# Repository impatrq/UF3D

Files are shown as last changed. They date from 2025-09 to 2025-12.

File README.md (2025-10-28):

# Bienvenido a UpFeet

<p align="center">
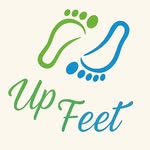
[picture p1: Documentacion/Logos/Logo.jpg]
UpFeet Logo
  
</p>

<div align="center">

🔗 Visitanos en  
👉 <a href="vzaccari33.wixsite.com/upfeet" target="_blank" rel="noopener noreferrer"><strong>nuestra pagina web</strong></a>

<br><br>

<a href="https://www.instagram.com/upfeet.3d/" target="_blank" rel="noopener noreferrer">
  Instagram
  @upfeet
</a>

</div>

---

## Nuestra Propuesta

**UpFeet3D** es un proyecto que desarrolla un escáner de pies basado en tecnología LiDAR y un sistema de ejes motorizados que permiten generar un modelo 3D preciso de la anatomía del pie. A partir de este escaneo, se diseña de manera automática una plantilla ortopédica personalizada que luego es fabricada mediante impresión 3D, ofreciendo una solución innovadora, accesible y adaptada a cada usuario.

---

## Cómo surgió el proyecto

El proyecto surgió a partir de la necesidad de brindar una solución a los pilotos y tripulaciones aéreas, quienes pasan largas horas sentados en condiciones que, sumadas a una mala pisada, pueden afectar la postura, generar dolores en la columna y aumentar la fatiga. Para atender esta problemática se diseñó un escáner portátil, que permite a una aerolínea contar con una sola máquina capaz de realizar plantillas personalizadas a todos sus empleados, reduciendo costos y facilitando la implementación. Con el tiempo, el desarrollo se proyectó también para otros usos, ofreciendo beneficios a cualquier persona que requiera una corrección postural o mayor confort en su andar.

---

## Características Principales

- Impresión 3D  
- Configuración por pantalla táctil  
- Escaneo 3D LiDAR  
- Sistema de ejes  
- Portátil  
- Económico  
- Rápido  

---

## Integrantes

- Melina Alfonso  
- Agustín Azorín  
- Eugenio Herrera  
- Tiago López  
- Victoria Viva  
- Valentín Zaccari  

---

## Información de Contacto

🌐 Sitio web oficial: [UpFeet Web](vzaccari33.wixsite.com/upfeet)  
📸 Instagram: [@UpFeet](https://www.instagram.com/upfeet.3d/) 📱🙌🎉  
📧 Correo: **upfeet3d@gmail.com**

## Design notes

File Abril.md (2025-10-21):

## Mes de Abril

**Objetivos del mes:**  
-  Crear todas los medios para publicar nuestos avances
-  Conseguir sponsors
-  Establecer los principios teoricos del proyecto

**Actividades realizadas:**  
-  Se creo la pagina web del proyecto
-  Se vrearon las redes sociales del proyecto
-  Se terminaron los objetivos de logro
-  Se termino el anteproyecto
-  Se subio infomacion del proyecto a las redes sociales
-  Se contacto via mail a diferentes empresas par buscar patrocinio
-  Se comenzo a investigar elementos necsarios para el proyecto
-  Se diseo como va a ser la estrucutra de la impresora

**Resultados obtenidos:**  
-  Se logro profundizar la interaccion con organismos como ortopedia IOA, ortopedia Pelaez, MicroElectronica, TP3D, ProyectoColor, Electrocomponentes S.A, etc.
-  Se consiguio materiales como los filamentos 3D, de parte de proyecto color, para el proyecto
-  Se consiguio algo de apoyo por parte de las reds sociales
-  El anteproyecto fue aprobado
-  Se decidio usar una Kinect ONE para la camara dl escaner
-  Se decidio usar FSR para los sensores de presion
-  Se decidio que materiales habria que usar para la construccion de la impresora

**Dificultades encontradas:**  
-  No se pudo lograr cubrir todo el proyecto a base de patrocinios

---

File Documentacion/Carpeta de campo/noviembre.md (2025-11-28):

## Mes de Noviembre

### Semana 1: Migración a Pi Pico y Fabricación de Nueva Placa de Control

**Objetivo de la semana:**
* Resolver la inestabilidad recurrente de la Raspberry Pi 4 (Pi 4) y migrar a un microcontrolador más fiable para la etapa de control.
* Diseñar y fabricar la nueva placa de control.

**Actividades realizadas:**
* Se realizaron pruebas para estabilizar la Pi 4 intentando el arranque a través de la salida **Micro HDMI** a monitores, pero la inestabilidad regresó después de poco tiempo.
* Se tomó la decisión de cambiar de microcontrolador, optando por la **Raspberry Pi Pico** debido a que se percibía como más simple y confiable para las tareas de control de motores.
* Se diseñó y se fabricó una **nueva placa de cobre** adaptada a la **Pi Pico**.
* En el nuevo diseño se tomaron medidas para mejorar la fiabilidad: se **agrandaron las pistas** y se hicieron las conexiones más cómodas.

**Resultados obtenidos:**
* Se decidió la **migración completa** del control de motores a la Pi Pico.
* Se completó el diseño y la fabricación de la **placa de control adaptada** al nuevo microcontrolador.

**Dificultades encontradas:**
* La persistente inestabilidad del *boot* y las conexiones de pines de la Raspberry Pi 4.

**Próximos pasos:**
* Probar la funcionalidad de los drivers y motores con la nueva placa.

***

### Semana 2: Control Estable de Motores, Integración LiDAR y Primeras Impresiones

**Objetivo de la semana:**
* Lograr el control total y estable de motores y sensor en la Pi Pico.
* Iniciar el testeo y la calibración de la impresora 3D.

**Actividades realizadas:**
* **Control de Motores:** Una vez fabricada la placa, se probaron los drivers y funcionaron perfectamente, **moviendo hasta dos motores paso a paso a la vez**. Se identificó que faltaba un driver operativo, se compró un reemplazo y, una vez instalado, **los tres motores funcionaron sin problemas**.
* **Integración LiDAR:** Se intentó testear el sensor LiDAR en la Pi Pico y **no funcionaba** (a pesar de funcionar en la Pi 4), un problema que resultó ser inusual. Tras diversas pruebas con códigos e invirtiendo el cableado, se descubrió que la única manera de que funcionara era **puentear el TX y RX del mismo LiDAR**. Esta corrección permitió seguir avanzando con el testeo del sensor.
* **Impresora 3D:** Se realizaron las primeras pruebas de impresión y **calibración** para el filamento **PETG**. Posteriormente, se realizó el **cambio de filamento a PLA**, con la calibración específica requerida para este material.

**Resultados obtenidos:**
* **Control de tres motores estable** y funcionando correctamente con la Pi Pico.
* Se implementó una **solución de *hardware*** (puenteo TX/RX) para el sensor LiDAR.
* Se **calibró la impresora** para los filamentos PETG y PLA.

**Dificultades encontradas:**
* Problema de comunicación inexplicable del LiDAR con la Pi Pico.

**Próximos pasos:**
* Fabricar los componentes mecánicos de acople

***

### Semana 3: Solución Mecánica Ingeniosa y Montaje Final del Escáner

**Objetivo de la semana:**
* Resolver los problemas de acoplamiento mecánico y ensamblar el sistema de escaneo completo.

**Actividades realizadas:**
* **Diseño e Impresión 3D:** Se diseñaron **tres acoples en AutoCAD** para las varillas roscadas de los ejes X e Y, y se buscaron y modificaron **dos soportes** para las varillas del eje Y. Todas estas piezas fueron **impresas en 3D con filamento PLA**.
* **Problema Anti-Backlash:** La **tuerca *anti-backlash* comprada no encajaba** con las varillas roscadas.
* **Solución Ingeniosa:** Se compraron **arandelas con tuercas a rosca** que sí coincidían con la varilla. Se procedió a **soldar la tuerca a la arandela** con un soldador eléctrico.
* Esta solución casera funcionó perfectamente, permitiendo que la varilla realizara los **movimientos horizontales y verticales** para el sensor LiDAR sin juego.
* **Ensamblaje Final:** Finalmente, se procedió a **unir y montar todo el escáner**, integrando la Pi Pico, los motores, el LiDAR y la estructura de ejes en H.

**Resultados obtenidos:**
* Se creó una **solución mecánica funcional y económica** para el problema de la tuerca *anti-backlash*.
* El **escáner fue completamente ensamblado y montado** en su estructura final.

**Dificultades encontradas:**
* Incompatibilidad de la tuerca *anti-backlash* comprada.

**Próximos pasos:**
* Pruebas de funcionamiento del sistema ensamblado y desarrollo de *software* de alto nivel.

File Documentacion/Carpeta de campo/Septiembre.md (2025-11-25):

## Día 1

**Integrantes presentes:**  
-  Melina Alfonso
-  Agustin Azorin 
-  Eugenio Herrera
-  Tiago Lopez
-  Victoria Viva
-  Valentin Zaccari

**Objetivo del día:**  
-  Adaptar el firmware para la skr
-  Hacer funcionar un motor con la raspberry pi 4

**Actividades realizadas:**  
-  Se probo un motor con la pi 4
-  Se realizaron pruebas y medidas individuales para intentar encontrar el problema dentro del circuito del motor de la pi 4

**Resultados obtenidos:**  
-  El motor no funciono
-  No se encontro el problema

**Dificultades encontradas:**  
-  No conocemos el motivo del fallo en el circuito del escaner

**Próximos pasos:**  
-  Encontrar el problema del circuito de la pi 4

---
## Día 3

**Integrantes presentes:**  
-  Melina Alfonso
-  Agustin Azorin 
-  Eugenio Herrera
-  Tiago Lopez
-  Victoria Viva
-  Valentin Zaccari

**Objetivo del día:**  
-  Adaptar el firmware para la skr
-  Hacer funcionar un motor con la raspberry pi 4

**Actividades realizadas:**  
-  Se probo un motor con la pi 4
-  Se realizaron pruebas y medidas individuales para intentar encontrar el problema dentro del circuito del motor de la pi 4

**Resultados obtenidos:**  
-  El motor no funciono
-  No se encontro el problema

**Dificultades encontradas:**  
-  No conocemos el motivo del fallo en el circuito del escaner

**Próximos pasos:**  
-  Encontrar el problema del circuito de la pi 4

---
## Día 5

**Integrantes presentes:**  
-  Melina Alfonso
-  Agustin Azorin 
-  Eugenio Herrera
-  Tiago Lopez
-  Victoria Viva
-  Valentin Zaccari

**Objetivo del día:**  
-  Adaptar el firmware para la skr
-  Hacer funcionar un motor con la raspberry pi 4

**Actividades realizadas:**  
-  Se probo un motor con la pi 4
-  Se realizaron pruebas y medidas individuales para intentar encontrar el problema dentro del circuito del motor de la pi 4

**Resultados obtenidos:**  
-  El motor no funciono
-  No se encontro el problema

**Dificultades encontradas:**  
-  No conocemos el motivo del fallo en el circuito del escaner

**Próximos pasos:**  
-  Encontrar el problema del circuito de la pi 4

---

## Día 8

**Integrantes presentes:**  
-  Melina Alfonso
-  Agustin Azorin 
-  Eugenio Herrera
-  Tiago Lopez
-  Victoria Viva
-  Valentin Zaccari

**Objetivo del día:**  
-  Terminar de adaptar el firmware para la skr
-  Hacer funcionar un motor con la raspberry pi 4

**Actividades realizadas:**  
-  Se probo un motor con la pi 4
-  Se realizaron pruebas y medidas individuales para intentar encontrar el problema dentro del circuito del motor de la pi 4

**Resultados obtenidos:**  
-  El motor no funciono
-  No se encontro el problema
-  Setermino de adaptar el firmware

**Dificultades encontradas:**  
-  No conocemos el motivo del fallo en el circuito del escaner

**Próximos pasos:**  
-  Encontrar el problema del circuito de la pi 4
-  Probar los Ejes de la impresora

---
## Día 10

**Integrantes presentes:**  
-  Melina Alfonso
-  Agustin Azorin 
-  Eugenio Herrera
-  Tiago Lopez
-  Victoria Viva
-  Valentin Zaccari

**Objetivo del día:**  
-  Verificar el funcionamiento de las salidas de la skr
-  Hacer funcionar un motor con la raspberry pi 4

**Actividades realizadas:**  
-  Se probo un motor con la pi 4 con la supervision del profesor Garabato
-  Se probo la alimentacion de la skr
-  Se probaron las salidas de los cooler de la skr
-  Se probaron las salidas de los motores de la skr
-  Se realizaron pruebas y medidas individuales para intentar encontrar el problema dentro del circuito del motor de la pi 4

**Resultados obtenidos:**  
-  El motor funciono parcialmente al principio pero luego dejo de funcionar
-  No se encontro el problema
-  Se comprobo el correcto funcionamiento de las salidas de la skr

**Dificultades encontradas:**  
-  No conocemos el motivo del fallo en el circuito del escaner

**Próximos pasos:**  
-  Encontrar el problema del circuito de la pi 4
-  Probar los Ejes de la impresora

---
## Día 11

**Integrantes presentes:**  
-  Melina Alfonso
-  Agustin Azorin 
-  Eugenio Herrera
-  Tiago Lopez
-  Victoria Viva
-  Valentin Zaccari

**Objetivo del día:**  
-  Probar Eje Y de la impresora
-  Probar Eje X de la impresora
-  Probar Eje Z de la impresora
-  Nivelar Eje Z de la impresora
-  Hacer funcionar un motor con la raspberry pi 4

**Actividades realizadas:**  
-  Se probo un motor con la pi 4 con la supervision del profesor Gabriel Arguello
-  Se probo la alimentacion de la skr
-  Se probaron las salidas de los cooler de la skr
-  Se probaron las salidas de los motores de la skr
-  Se realizaron pruebas y medidas indivuduales para intentar encontar el problema dentro del circuito del motor de la pi 4

**Resultados obtenidos:**  
-  El motor no arranco
-  Se comprobo el correcto funcionamiento de las salidas de la skr

**Dificultades encontradas:**  
-  Las medidas dieron como resultado que en la enrda dl step estaban llegando 1.6V y no 3.3V como se esperaba

**Próximos pasos:**  
-  Encontrar una forma de amplificarel voltajedado por la pi 4 en la entada del STEP
-  Probar los Ejes de la impresora

---
## Día 12

**Integrantes presentes:**  
-  Melina Alfonso
-  Agustin Azorin 
-  Eugenio Herrera
-  Tiago Lopez
-  Victoria Viva
-  Valentin Zaccari

**Objetivo del día:**  
-  Hacer funcionar un motor con la raspberry pi 4 

**Actividades realizadas:**  
-  Nuevo cableado d los ejes Z e Y de la impresora
-  Se realizo un diagrama para agregar un comparador al circuito de la pi 4
-  Se intento arrancar el motor con este nuevo circuito
-  Se realizaron pruebas y medidas individuales para intentar encontar el problema dentro del circuito del motor de la pi 4

**Resultados obtenidos:**  
-  El motor no arranco
-  No se encontro el problema
-  Se comprobo el funcionaminto del nuevo cableado

**Dificultades encontradas:**  
-  El motor de la pi 4 no arranco

**Próximos pasos:**  
-  Encontar el problema del circuito de la pi 4

---
## Día 15

**Integrantes presentes:**  
-  Melina Alfonso
-  Agustin Azorin 
-  Eugenio Herrera
-  Tiago Lopez
-  Victoria Viva
-  Valentin Zaccari

**Objetivo del día:**  
-  Verificar el funcionamiento d las salidas de la skr
-  Haver funcionar un motor con la raspberry pi 4

**Actividades realizadas:**  
-  Homing Eje Y y Eje X
-  Comprobar fines de carrera del Eje X
-  Se probo el nuevo circuito para el motor del escaner con el comparador bajo la supervision de Gabriel Arguello
-  Se realizaron pruebas y medidas indiviudales para intentar encontar el problema dentro del circuito del motor de la pi 4
-  Se realizo el esquematico y el pcb para este nuevo circuito

**Resultados obtenidos:**  
-  El motor arranco parcialmente, se movia cuando se tocaba un cable en especifico
-  No se encontro el problema
-  Se comprobo correctamente los fines de carrera
-  Se completo con exito el homing de los Ejes X e Y

**Dificultades encontradas:**  
-  Se cree que el error puede ser culpa de los cables

**Próximos pasos:**  
-  Solucionar el problema del circuito de los motores del escaner o imprimir el pcb
-  Homing Eje Z

---
## Día 16

**Integrantes presentes:**  
-  Melina Alfonso
-  Agustin Azorin 
-  Eugenio Herrera
-  Tiago Lopez
-  Victoria Viva
-  Valentin Zaccari

**Objetivo del día:**  
-  Hacer funcionar un motor con la raspberry pi 4

**Actividades realizadas:**  
-  Conexion en paralelo de los sensores Z1 minimo y Z2 minimo
-  Se realizo un diagrama para un circuito con un rele y uno para un circuitocon un tansistor parael circuito del motor por las recomendaciones de un profesor
-  Se probaron ambos esquemas
-  Se probo el motor usando el compardor y asegurando una buena conexion
-  Se realizaron pruebas y medidas indiviudales para intentar encontar el problema dentro del circuito del motor de la pi 4

**Resultados obtenidos:**  
-  Ninguno de los esquemas funciono
-  No se encontro el problema
-  Las conexiones en paralelo resultaron exitosas

**Dificultades encontradas:**  
-  El motor de la pi 4 no arranco
-  Se sospecha que es por culpa de los cables

**Próximos pasos:**  
-  Encontar el problema del circuito de la pi 4
-  Probar los Ejes de la impresora

---
## Día 17

**Integrantes presentes:**  
-  Agustin Azorin 
-  Eugenio Herrera (Falto por enfermedad)
-  Tiago Lopez
-  Victoria Viva
-  Valentin Zaccari

**Objetivo del día:**  
-  Hacer funcionar un motor con la raspberry pi 4
-  Hacer el homing del Eje Z

-  
**Actividades realizadas:**  
-  Se probo un motor con la pi 4 con la supervision de Fabrizio Karlassara
-  

**Resultados obtenidos:**  
-  El motor finalmene funciono
-  Se encinto la tira de pines del motor para que no generen falso contacto
-  Se prescindio dl comparador

**Dificultades encontradas:**  
-  Se encontaron varios drivers disfuncionales

**Próximos pasos:**  
-  Realizar el esquematico y el pcb para el nuevo circuito

---
## Día 18

**Integrantes presentes:**  
-  Melina Alfonso
-  Agustin Azorin 
-  Eugenio Herrera
-  Tiago Lopez

**Objetivo del día:**  
-  Realizar el pcb y el esquematico del nuevo circuito para el escaner
-  Completar el Homing del Eje Z
**Actividades realizadas:**  
-  Se probo un motor con la pi 4 con la supervision de Arguello Gabriel
-  Se desmonto una impresora 3D vieja para intentar conseguir componentes necesarios
-  Se intento hacer el homing del Eje Z 

**Resultados obtenidos:**  
-  Se termino el pcb y el esquematico
-  Se consiguiron unos cuantos componentes de la impresora vieja
-  

**Dificultades encontradas:**  
-  No se conmsiguieon los acoples buscados

**Próximos pasos:**  
-  Imprimir el pcb.

---
## Día 22

**Integrantes presentes:**  
-  Melina Alfonso
-  Agustin Azorin 
-  Eugenio Herrera
-  Tiago Lopez
-  Valentin Zaccari

**Objetivo del día:**  
-  Probar dos motores a la vez
-  Imprimir el pcb para la placa
-  

**Actividades realizadas:**  
-  Se probaron dos motores a la vez
-  Homing del Eje Z

**Resultados obtenidos:**  
-  Se logro que ambos funcionen al mismo tiempo acorde al esquema realizado

**Dificultades encontradas:**  
-  Se encontro que uno de los drivers no funcionaban

**Próximos pasos:**  
-  Comprar una placa de cobre
-  Comprar borneras
-  Pegar el pcb a la palca y pasarla por acido
-  Agujerear la placa

**Actividades realizadas:**  
-  Se probaron dos motores a la vez
-  Homing del Eje Z

**Resultados obtenidos:**  
-  Se logro que ambos funcionen al mismo tiempo acorde al esquema realizado

**Dificultades encontradas:**  
-  Se encontro que uno de los drivers no funcionaban

**Próximos pasos:**  
-  Comprar una placa de cobre
-  Comprar borneras
-  Pegar el pcb a la palca y pasarla por acido
-  Agujerear la placa

---
## Día 23

**Integrantes presentes:**  
-  Melina Alfonso
-  Agustin Azorin 
-  Eugenio Herrera
-  Tiago Lopez
-  Victoria Viva
-  Valentin Zaccari

**Objetivo del día:**  
-  Comprar las cosas que faltan
-  Probar todos los Homing juntos

**Actividades realizadas:**  
-  Se fueron a comprar las borneras, una ficha de DB15 dos filas y una placa de cobre que faltaban

**Resultados obtenidos:**  
-  Compras exitosas

**Dificultades encontradas:**  
-  
-  Dos drivers se quemaron en el proceso de prueba de la impresora

**Próximos pasos:**  
-  Encontrar el problema del circuito de la pi 4
-  Probar los Ejes de la impresora

---

30 de septiembre:

**objetivo del dia:** terminar la simulacion del escaneo

**actividades realizadas:** realizamos testeo de los nuevos driver que llegaron  para los motores paso a paso.
testeamos uno por uno su optimo funcionamiento y empezamos a realizar el codigo para combinar el movimiento de motor mas la lectura del lidar simulando el escaneo punto por punto.

**dificultades encontradas:**
-  tuvimos problemas para entrar a la terminal de la pi4 por un cambio en la ip

-  los drivers y el lidar no funcionaban por un problema de cableado y de limite de corriente que tuvimos que ampliar para su funcionamiento.

-  las vueltas y los pasos del motor no estaban directamente relacionados, lo corregimos cambiando unas lineas de codigo.

**resultados obtenidos:**

-  los motores giraron con los nuevos drivers

-  se logro y se mejoro que ambos motores giren en simulteando mientras trabajaban con el Lidar.

-  se logro realizar la simulación del escaneo.

**siguientes paso:** 
-  comprar tiras de pines
-  terminar de corregir la placa
-  soldar los componentes

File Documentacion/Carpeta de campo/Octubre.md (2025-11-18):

## Mes de Octubre

### Semana 1 de octubre: Depuración de la Placa de Cobre Prototipo

**Objetivo de la semana:**
* Finalizar el ensamblaje y la corrección de la primera versión de la placa de cobre de control de motores.
* Realizar las primeras pruebas funcionales de los motores y el sensor.

**Actividades realizadas:**
* Se realizó una intensa labor de **soldadura y desoldadura** de componentes para asegurar la continuidad de las pistas.
* Se encontraron y corrigieron múltiples **cortocircuitos** donde las patas tocaban la línea de tierra (GND) debido al diseño compacto de la placa.
* Se tuvieron que **desoldar borneras** para acceder y corregir las pistas.
* Se reubicó una **bornera en el lado opuesto** para facilitar las conexiones.
* Se corrigieron fallos donde las **patas de los componentes no hacían contacto** correcto con el estaño.
* Se iniciaron las pruebas de funcionamiento: probando **uno y dos motores más el sensor**. Los motores que giraban lo hacían con **muchísimo ruido y vibraciones**, y consumían más corriente de lo normal.
* El tercer motor no funcionó.

**Resultados obtenidos:**
* La placa de control fue ensamblada y corregida, lista para pruebas.
* Detección de problemas de **ruido/vibración** en los motores y **fallo** en el tercer motor.

**Dificultades encontradas:**
* Múltiples errores de soldadura y problemas de cortocircuitos por la complejidad del diseño.

**Próximos pasos:**
* Diagnosticar la causa del ruido y el fallo del tercer motor.

***

### Semana 2 de octubre: Diagnóstico Crítico y Fallo de Componentes

**Objetivo de la semana:**
* Resolver problemas de ruido/vibración y diagnosticar el fallo del tercer motor.
* Solucionar un fallo crítico en la Raspberry Pi 4 (Pi 4).

**Actividades realizadas:**
* Se descubrió que la causa del **ruido y las vibraciones** venía de los **cables conectores del motor**, que estaban **derretidos** y causaban un mal contacto. Una vez reemplazados, los dos motores funcionaron perfectamente.
* Se diagnosticó el fallo del tercer motor, sospechando del driver. Se **desoldó el driver** y se probó, confirmando que el **GND y VCC estaban en cortocircuito interno** (componente defectuoso de fábrica). Tuvimos que conseguir otro driver nuevo.
* Durante estas pruebas, la **Pi 4 tuvo un fallo**: no reconocía la Micro SD porque el **zócalo se había desprendido**.
* Se investigó la solución y se logró **instalar el sistema operativo en un USB** y configurar la Pi 4 para que **arrancara desde el USB**, reviviendo la placa.

**Resultados obtenidos:**
* **Ruido y vibración de motores resueltos**.
* **Pi 4 recuperada** con éxito mediante la configuración de arranque por USB.
* Detección de un **driver de motor defectuoso**.

**Dificultades encontradas:**
* Fallo físico del zócalo SD de la Pi 4.
* Componente defectuoso (driver) que impidió la operación completa.

**Próximos pasos:**
* Probar la placa con el driver nuevo.

***

### Semana 3 de octubre: Deterioro de la Placa y Rediseño Definitivo

**Objetivo de la semana:**
* Probar la funcionalidad completa con el nuevo driver.
* Diseñar y ensamblar una nueva placa de control (Versión Definitiva) debido al deterioro del prototipo.

**Actividades realizadas:**
* Una vez con el driver nuevo, al intentar probar la placa, **ninguno de los tres drivers y motores funcionó**. Los motores consumían corriente, pero no giraban.
* Se descubrió que la **placa de cobre prototipo estaba seriamente deteriorada**: el cobre estaba **levantado y quemado** cerca de los conectores de la Pi 4 debido a las pruebas y fallos de corriente, además de presentar oxidación.
* Se tomó la decisión de **desechar la placa prototipo** y construir una **nueva desde cero** para asegurar la fiabilidad.
* Se **desoldaron todos los componentes** y se compraron una nueva placa de cobre y conectores.
* Se procedió a **fabricar la placa de nuevo**, corrigiendo las pistas y **mejorando el diseño** para crear la **versión definitiva** del circuito de control.

**Resultados obtenidos:**
* Se constató el **fallo total y deterioro físico** de la placa prototipo.
* Se inició el proceso de **rediseño y fabricación de la placa de control definitiva**.

**Dificultades encontradas:**
* Fallo irreversible de la placa prototipo, obligando a un reinicio de la fase de ensamblaje.

**Próximos pasos:**
* Ensamblar y testear la nueva placa definitiva.

***

### Semana 4 de octubre: Nuevos Componentes y Avances en Impresora

**Objetivo de la semana:**
* Adquirir componentes mecánicos para el sistema de ejes en H.
* Integrar la nueva placa madre y poner en funcionamiento el extrusor de la impresora 3D.

**Actividades realizadas:**
* Se investigaron y compraron **tuercas anti-backlash** y los **acoples** necesarios para las varillas roscadas, avanzando en los componentes del **sistema de ejes en H** para el escáner.
* Con la nueva placa definitiva realizada, se testó nuevamente: solo **funcionó un driver de motor y el sensor LiDAR**.
* Se encontró que la **Pi 4 se desconectaba fácilmente** de los pines y el proceso de **arranque (bootear)** era **muy irregular**, lo que causaba grandes retrasos. Se inició la investigación de alternativas.
* Se implementó la solución para el control de la impresora: se instaló y se configuró el **pinout de la placa madre SKR 1.4**.
* Se comenzó a usar la **fuente de la impresora** para alimentar la nueva placa madre.
* Se tuvo que realizar un **cable DB25 casero** y comprar las fichas para realizar conexiones.
* Se realizaron ajustes en la configuración de *firmware* (`Klipper`): se cambió el **fin de carrera de X2 por Z2**.
* El **eje Z presentó problemas de falso contacto** en sus conexiones, lo que requirió diagnóstico.
* Finalmente, se **eliminó el cable DB25 casero** y se conectó el **extrusor directamente** a la placa mediante cables, simplificando la conexión.
* Se logró poner en **funcionamiento el extrusor con filamento**, demostrando que el subsistema de fabricación de la plantilla estaba operativo.

**Resultados obtenidos:**
* Adquisición de **componentes clave** para el sistema de ejes del escáner.
* **Extrusor de la impresora 3D operativo** y probado con filamento.
* Detección de una nueva dificultad: **inestabilidad en la conexión y el arranque de la Pi 4**.

**Dificultades encontradas:**
* Persistencia de fallos en el control de motores y el arranque irregular de la Pi 4.
* Dificultades de conectividad (falso contacto en eje Z) y necesidad de simplificar el cableado (eliminación del DB25).

**Próximos pasos:**
* Encontrar una solución definitiva para la inestabilidad de la Pi 4.
* Solucionar el fallo en el control de los tres motores.

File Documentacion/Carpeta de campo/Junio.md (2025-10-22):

cambiar la kinect por otro sensor
investigar otra camara
impresora de la escuela
disear forma de usar el nuevo sensor
arreglando fin de carrera de la impresora de la escuela

## Semana del 2

**Objetivos de la semana:**  
-  Verifificar funcionamiento de la impresora de la escuela
-  Encontrar la solucion al fallo de la fuente de alimentacion de la impresora
-  Decidir que sensores usar

**Actividades realizadas:**  
-  Se intento conectar y encender la impresora
-  Se hicieron consultas y pruebas para encontar que ocaciono el fallo del fusible
-  Se fueron a comprar las cosas necesarias para solucionar el problema
-  Se cambio el fusible
-  Se invesigaron distintos sensores de presion

**Resultados obtenidos:**  
-  La impresora no encendio
-  Se compraron un potenciometro, unas lijas y unos tornillos
-  Decidimos usar TESCAN en vez de FSR

**Dificultades encontradas:**  
-  El fusible estallo por culpa de un corto, tuvimos que cambiarlo
-  No encontramos Tescan ni FSR en mercado libre a un preio razonable

**Próximos pasos:**  
-  Solucionar el error que causo la falla en la fuente de alimentacion
-  Comprar los sensores

---

## Semana del 9

**Objetivos de la semana:**  
-  Comprar los sensores
-  Terminar de arreglar la fuente de alimentacion
-  Subir avances a nuestra pagina

**Actividades realizadas:**  
-  Se hicieron los ajustes en la placa de la fuente de alimentacion para solucionar sus problemas
-  Se conecto e intento enceder la impresora
-  Se invetigo y consulto con distintos profesores para decidir donde comprar los sensores
-  Se hicieron distintas publicaciones para demostrar nuestros avances

**Resultados obtenidos:**  
-  La impresora encendio correctamente
-  Se decidio volver a los FSR debido a que los TESCAN se encontraban unicamente en china a sobreprecio
-  Las publicaciones tuvieron buen impacto

**Dificultades encontradas:**  
-  El fusible estallo por culpa de un corto, tuvimos que cambiarlo

**Próximos pasos:**  
-  Solucionar el error que causo la falla en la fuente de alimentacion

---

## Semana del 18

**Objetivos de la semana:**  
-  Desarrollar el codigo para la lectura de los datos de presion
-  Se investigo donde comprar los FSR
-  Desarrollar el codigo para la utilzacion de esos datos
-  Seguir investigando la impresora donada de la escuela

**Actividades realizadas:**  
-  Se desarrollaron y probaron en una simulacion los codigos mencionados
-  Se siguio viendo que cosas funcionaban de la impresora y cuales no

**Resultados obtenidos:**  
-  Se determino que habia que conseguirle una nueva placa madre. una cama magnetica y limpiar la placa caliente
-  Ambos codigos funcionaron corrwectamente en la simulacion
-  No se encontro un lugar por el que comprar los FSR

**Dificultades encontradas:**  
-  Se encontro que los fines de carrera d la impresora no funcionaban correctamente
-  Se encontro un problema en la kinect que afectaba al proyecto

**Próximos pasos:**  
-  Investigar por cual ota camara reemplazar la kinect
-  Repara los fines de carrera

---

## Semana del 25

**Objetivos de la semana:**  
-  Reparar los fines de carrera
-  Encontrar un reemplazo de la kinect

**Actividades realizadas:**  
-  Se repararon y probaron los fines de carrera
-  Se investigaron diversos reemplazos para la kinect
-  Mandamos a comprar el sensor sustituto 

**Resultados obtenidos:**  
-  Los fines de carrera volvieron a funcionar los fines de carrera
-  Se decidio comprar un sesnsor LiDar

**Dificultades encontradas:**  

**Próximos pasos:**  
-  Probar un motor con la pi 4
-  Porbar el sesnor LiDaar con la pi 4

---

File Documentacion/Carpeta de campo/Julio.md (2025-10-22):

## Mes de Julio (Actividad Concentrada en las Primeras Dos Semanas)

### Semana 1 de julio

**Objetivo de la semana:**
* Evaluar el funcionamiento de los motores paso a paso.
* Modificar la estructura de la impresora 3D para mejorar la portabilidad del proyecto.

**Actividades realizadas:**
* Se realizaron **pruebas de funcionamiento de los motores paso a paso** utilizando un generador de funciones para verificar su respuesta, par y velocidad.
* Se realizó una **modificación física a la impresora 3D** que nos habían prestado: se procedió a **cortar su altura** para reducir su tamaño y aumentar significativamente la portabilidad del sistema.
* Se creó una **presentación en PowerPoint** para documentar y anunciar los avances clave logrados durante la primera mitad del año escolar.

**Resultados obtenidos:**
* Se **validó el funcionamiento básico** de los motores paso a paso.
* La impresora 3D fue **reducida de tamaño**, mejorando la portabilidad del proyecto.
* Se obtuvo una **presentación de avance** formalizada.
* Se decidio usar la impresora donada por proyecto color

**Dificultades encontradas:**

**Próximos pasos:**
-  Realizar pruebas del motor con la pi 4
-  Realizar pruebas del sensor con la pi 4
---

### Semana 2 de julio

**Objetivo de la semana:**
* Diagnosticar el hardware de la impresora 3D y tomar decisiones sobre el proyecto.

**Actividades realizadas:**
* Se avanzó en la definición del sistema de ejes, incluyendo: la elección de **varillas**, el **material** de la estructura, el **recorrido del escaneo** y las **medidas** específicas.
* Se realizaron **pruebas con el sensor LiDAR**.
* Se realizo la primer prueba de un motor con la pi 4
* Se **midieron todos los pines** de la placa de la impresora para encontrar las especificaciones necesarias y buscar una **nueva placa madre** compatible, ya que la original no funcionaba.
* Se realizó un análisis exhaustivo de costos y viabilidad, lo que llevó a la decisión final de **eliminar los sensores de presión** del proyecto debido a su alto costo y la dificultad para conseguir modelos adecuados.

**Resultados obtenidos:**
* Se obtuvo un **diseño teórico avanzado** del sistema de ejes para el escáner.
* Se documentaron todas las **medidas de pines** de la placa para la búsqueda del reemplazo.
* Se simplificó el alcance del proyecto al **descartar los sensores de presión**.

**Dificultades encontradas:**
* El **LiDAR no funcionó correctamente** durante las pruebas, deteniendo el avance en la etapa de escaneo.
* El motor no arranco

**Próximos pasos:**
* Durante agosto, el foco será solucionar el problema del LiDAR y adquirir la nueva placa madre y componentes.

---

semana 3 y 4: receso inveral

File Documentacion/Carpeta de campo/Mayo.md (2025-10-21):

### Semana 1 de mayo

**Objetivo de la semana:**
* Definir los materiales clave para la plantilla ortopédica y buscar la colaboración de especialistas.
* Iniciar el diseño conceptual del proyecto, incluyendo el escáner y la adquisición del microcontrolador principal.

**Actividades realizadas:**
* Se investigaron y analizaron diversos **materiales de amortiguación** para la plantilla, decidiéndose finalmente por la **Goma Eva** debido a sus propiedades y viabilidad. También se investigaron métodos de sujeción.
* Se contactó y se reunió con un **médico especialista** que brindó asesoramiento crucial sobre **plantillas ortopédicas**, sus beneficios y las principales causas de su necesidad, enriqueciendo la base teórica del proyecto.
* Se comenzó a investigar la adquisición del microcontrolador principal, la **Raspberry Pi 4 (Pi 4)**. Inicialmente se buscó de segunda mano, pero el alto precio dificultó la compra. Finalmente, se gestionó un **préstamo de una Pi 4** por parte del colegio.
* Se contactó a un **potencial socio** para el proyecto, pero las negociaciones no llegaron a concretarse.

**Resultados obtenidos:**
* Se definió la **Goma Eva** como el material principal de amortiguación.
* Se obtuvo **información médica especializada** fundamental para el diseño.
* Se consiguió una **Raspberry Pi 4 prestada**, solucionando el problema del microcontrolador.

**Dificultades encontradas:**
* La dificultad para conseguir la Raspberry Pi 4 a un precio accesible.

**Próximos pasos:**
* Iniciar el trabajo con la Raspberry Pi 4.
* Enfocarse en la adquisición y diseño de la estructura del escáner.

---

### Semana 2 de mayo

**Objetivo de la semana:**
* Asegurar el hardware de la impresora 3D  mediante un patrocinio.
* Iniciar la programación y la simulación del prototipo.

**Actividades realizadas:**
* Se contactó a una **empresa** que ofreció colaborar, proporcionándonos una **impresora 3D en mal estado** para que la restableciéramos y usáramos.
* Se visitó la empresa para formalizar el **acuerdo de colaboración**, comprometiéndonos a **publicitar** su marca a cambio del uso de la impresora.
* Se **creó contenido para redes sociales** junto a la empresa y el médico, cumpliendo con los primeros compromisos de publicidad.
* Se investigaron los **lenguajes y tecnologías** necesarios para la programación de la plantilla y el procesamiento de datos.
* Se creó un **programa prototipo inicial** para la generación del modelo 3D de la plantilla.

**Resultados obtenidos:**
* Se aseguró una **impresora 3D** para el proyecto.
* Se **inició la fase de programación** con la creación del programa prototipo.

**Dificultades encontradas:**
* Coordinación inicial de la colaboración y el contenido publicitario.

**Próximos pasos:**
* Retirar la impresora dañada.
* Integrar la Raspberry Pi 4 y simular los datos de escaneo.

---

### Semana 3 de mayo

**Objetivo de la semana:**
* Integrar el microcontrolador y el software prototipo.
* Iniciar el diagnóstico de la estructura del escáner (Kinect) y los sensores de presión.

**Actividades realizadas:**
* Se logró **acceder a la terminal de la Raspberry Pi 4**, permitiendo empezar a trabajar en el entorno de desarrollo.
* Se **simularon datos** de los futuros **sensores de presión** y la **Kinect futura** en un algoritmo.
* Se probó el algoritmo de simulación con el programa prototipo creado anteriormente, buscando simular el proceso de creación de la plantilla de principio a fin.
* Se realizaron las primeras investigaciones para encontrar el sensor de escaneo, identificando a la **Kinect** como la opción inicial, y se buscaron **precios de segunda mano**.
* Se empezó a analizar el **diseño y la estructura de la impresora casera** prestada para determinar sus medidas, materiales y detalles para su reparación y uso.
* Se creó una **lista de componentes** de repuesto necesarios para la impresora.

**Resultados obtenidos:**
* La Raspberry Pi 4 quedó lista para el trabajo.
* Se consiguió la **simulación inicial de todo el proceso de la plantilla** (del escaneo a la generación del modelo 3D).

**Dificultades encontradas:**
* Surgieron **problemas con el algoritmo prototipo de prueba** y su integración con los datos simulados.

**Próximos pasos:**
* Definir la estructura general del proyecto.
* Enfocarse en el diagnóstico de la Kinect y el diseño del circuito de sensores.

---

### Semana 4 de mayo

**Objetivo de la semana:**
* Finalizar la adquisición del hardware inicial y resolver los problemas de diseño de sensores.
* Definir la estructura electrónica del escáner.

**Actividades realizadas:**
* Se fue a **retirar la impresora 3D dañada** que había proporcionado la empresa colaboradora.
* Se analizó y discutió la **estructura general del proyecto**, buscando soluciones a los problemas detectados y definiendo posibles caminos a seguir.
* Se investigó y analizó la **portabilidad** general que debía tener el producto final.
* Se realizaron investigaciones para el **esquemático** de la placa electrónica del escáner.
* Se encontraron serias **dificultades para encontrar una Kinect**, ya que estaban descontinuadas y escaseaban. Además, se identificó la necesidad de un **adaptador** específico, lo cual complicaba aún más la adquisición.
* Se investigó la **ubicación de los sensores de presión**, ya que se encontró que podían **tapar la visión de la Kinect** durante el escaneo. Se propuso una solución inicial: **dividir el escaneo del pie y la toma de datos de presión en dos etapas separadas**.
* Se investigó el posible uso de un **multiplexor**, dada la potencial gran cantidad de entradas de sensores de presión, para poder leerlos todos con una única salida.
* Se analizó el **diseño inicial de la caja donde se apoyaría el pie**, detallando materiales, componentes y cómo se ensamblaría como prototipo.

**Resultados obtenidos:**
* Se obtuvo el **hardware principal de fabricación** (impresora dañada).
* Se definió la solución de **separar las etapas de escaneo y presión**.
* Se identificaron los problemas de escasez de la **Kinect**.

**Dificultades encontradas:**
* La escasez de la Kinect y la necesidad del adaptador forzaron a considerar la viabilidad del escáner.

**Próximos pasos:**
* Reparación de la impresora 3D y búsqueda de un reemplazo para el Kinect.

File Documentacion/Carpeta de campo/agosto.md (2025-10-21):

### Semana 1 de agosto

**Objetivo de la semana:**
* Investigar y definir los componentes principales para la impresora 3D, incluyendo la placa base, el display y el firmware.
* Estudiar el funcionamiento del sensor LiDAR y su integración con la Raspberry Pi 4.

**Actividades realizadas:**
* Se investigaron diversas opciones de **placas madre** (`SKR`, `RAMPS`, `MKS`) para impresoras 3D, analizando sus características y compatibilidad con el proyecto.
* Se exploraron diferentes tipos de **displays** para la interfaz de usuario.
* Se llevó a cabo una investigación profunda sobre el **funcionamiento del sensor LiDAR** y su conexión con la **Raspberry Pi 4**.
* Se realizaron pruebas del sensor LiDAR utilizando un código genérico, y al no funcionar, se investigó y adaptó un nuevo código de internet para su correcto funcionamiento.

**Resultados obtenidos:**
* Se identificaron posibles opciones para la placa y el display.
* Se logró hacer funcionar el sensor LiDAR con la Raspberry Pi 4, permitiendo la lectura de datos. 

**Dificultades encontradas:**
* El código inicial para el sensor LiDAR no funcionaba, lo que requirió una investigación y adaptación adicionales para encontrar una solución.
* La gran variedad de placas y displays en el mercado hizo difícil la elección inicial.

**Próximos pasos:**
* Tomar una decisión final sobre la placa madre y el display que se comprarán.
* Comenzar con la investigación y adaptación del firmware (`Klipper`) para la placa seleccionada.

---

### Semana 2 de agosto

**Objetivo de la semana:**
* Decidir y adquirir los componentes clave del proyecto: la placa base y la cama magnética.
* Iniciar el diseño de la estructura del escáner.

**Actividades realizadas:**
* Se finalizó la investigación sobre las placas madre.
* Se investigo y compro la **camas magnéticas**.
* Se comenzó a diseñar la **estructura del escáner en AutoCAD**, basándose en las necesidades del proyecto y las dimensiones de los componentes.
* Se desarmó un extrusor para entender su funcionamiento interno y los componentes que lo integran.
* Se contacto a una metalurgia que fabrique y patrocine la estructura del escaner

**Resultados obtenidos:**
* Se realizó la compra de la placa madre (SKR) y la cama magnética .
* Se completó la primera versión del diseño de la estructura mecánica en AutoCAD.
* Se comprendió mejor el funcionamiento de un extrusor, lo que proporcionó conocimientos útiles para el proyecto.

**Dificultades encontradas:**
* Ajustar el diseño en AutoCAD para que fuera lo más eficiente posible en términos de materiales y funcionalidad.

**Próximos pasos:**
* Concretar una reunion con la metalurgia
* Conseguir el firmware para la placa madre
* Conseguir varillas para el sistema de ejes
---

### Semana 3 de agosto

**Objetivo de la semana:**
* Presentar el diseño de la estructura a la metalúrgica y coordinar su fabricación.
* Continuar con la investigación de los motores para el escáner.
* Conseguir las varillas

**Actividades realizadas:**
* Se realizó una reunión con la metalurgia para explicarles en detalle el plano. Sin embargo, debido a una falta de entendimiento por parte del fabricante, se tuvieron que hacer **correcciones y ajustes** en el diseño.
* Se compraron las varillas enroscadas y lisas
* Se mandaron a cortar a Newton par conseguir las medidas requeridas

**Resultados obtenidos:**
* Se corrigió el diseño de la estructura para que la metalúrgica pudiera entenderlo y fabricarlo correctamente.
* Se adquirieron conocimientos teóricos sobre el funcionamiento de los motores paso a paso.
* Se consiguieron y cortaron las varillas

**Dificultades encontradas:**
* La comunicación con la metalúrgica fue complicada al principio, lo que requirió una segunda reunión para aclarar el diseño.
* No se pudo conseguir una version adecuada de klipper para la SKR por lo que tuvimos que cambiar a Marlin

**Próximos pasos:**
* Esperar a que la metalúrgica fabrique la estructura y luego ir a buscarla.
* Encontar una version compatible de marlin

---

### Semana 4 de agosto

**Objetivo de la semana:**
* Recoger la estructura metálica finalizada.
* Haer funcionr un motor con la pi 4

**Actividades realizadas:**
* Se fue a la metalúrgica a **buscar la estructura del escáner** una vez terminada.
* Se probo el motor de la pi 4 en protoboard
* Se enntro y emepzo a adaptar una version comptible de marlin con la skr

**Resultados obtenidos:**
* Se obtuvo la estructura final, lista para el ensamblaje.
* Los motores no arrancaron.

**Dificultades encontradas:**

**Próximos pasos:**
* En la siguiente etapa, se procederá al **montaje de los componentes electrónicos** (placa, motores, LiDAR) en la estructura.

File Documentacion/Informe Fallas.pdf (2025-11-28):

### Impresora 3d

1.Explicación del problema

El día 15 de noviembre, durante la feria de ciencias, se produjo una falla eléctrica que provocó la quema de la placa madre de la impresora 3D. El incidente se originó de manera repentina mientras la impresora se encontraba conectada, y su efecto inmediato fue la interrupción total del funcionamiento del sistema de potencia de la placa.

Además, al momento del incidente, la impresora estaba conectada a una zapatilla eléctrica que alimentaba varias computadoras, todas funcionando al mismo tiempo y utilizando alargues adicionales, lo cual incrementa la carga total sobre la línea. A esto se sumaba la presencia de dos fuentes de 24 V perteneciente al escáner.

Aunque las fuentes no tenían relación directa con la impresora, el hecho de que varios equipos de alto consumo compartieran una misma toma múltiple aumenta significativamente la posibilidad de caídas de tensión, fluctuaciones, picos eléctricos o sobrecarga
momentánea en la red.
Este tipo de condiciones puede generar inestabilidad en la alimentación, afectando directamente a los componentes más sensibles de la placa madre, como el regulador de tensión y el MOSFET Q2, que terminan siendo los más propensos a dañarse cuando la línea eléctrica no se mantiene estable.
1.1. Componentes quemados.

1.1.a. Regulador de tensión:

El componente principal afectado fue el regulador de tensión, ya que este presentaba daños visualmente. Este componente, ubicado en la salida directa del puerto de alimentación principal, mostraba daños visibles de quemadura, lo que permitió determinar rápidamente qué había fallado y que era la causa principal de la interrupción en la distribución correcta del voltaje. Este regulador es el encargado de estabilizar y distribuir correctamente los voltajes requeridos por los distintos sectores de la placa. Además mediante mediciones con el multímetro se comprobó que el regulador impedía la correcta distribución del voltaje dentro del circuito, generando inestabilidad y falta de alimentación en determinadas zonas de la placa. Esto confirmó que el defecto del regulador no era solo físico, sino también funcional.

1.1.b. Mosfet Q2:

También se detectó que el MOSFET Q2 (modelo WSK220N04), ubicado en la misma zona de regulación, se encontraba completamente quemado. Este MOSFET es un componente esencial para manejar corrientes elevadas, especialmente en cargas de alta potencia como el cartucho calefactor del hotend o la cama caliente. Su destrucción confirma que la falla no había sido un evento aislado, sino que afectó a varios componentes.

Al realizar las mediciones correspondientes sobre el MOSFET Q2, se detectó que el componente no funcionaba correctamente. El multímetro registró una resistencia aproximada de 1,84 Ω entre sus terminales, un valor extremadamente bajo para este tipo de dispositivo. Una resistencia despreciable, lo que indica la presencia de un cortocircuito interno dentro del MOSFET.

Este comportamiento confirma que el componente se encuentra dañado o quemado, ya que un MOSFET en buen estado no debería presentar continuidad tan baja entre drenador y fuente.

1.1.c. Salidas HE0 y HE1

Son salidas de potencia controladas por la placa madre y están diseñadas para alimentar cargas resistivas de alto consumo, como los cartuchos calefactores del hotend. Cada salida controla la activación y regulación de la temperatura mediante un MOSFET, el cual enciende o corta el flujo de corriente según las órdenes del firmware.HE0 es la salida principal del hotend, mientras que HE1 se utiliza para un segundo extrusor.

Se evaluaron los MOSFETs correspondientes a las salidas HE0 y HE1 (modelo CDTO3N005). Al medirlos con el multímetro se observó continuidad entre Gate y Source, registrando aproximadamente 16,4 Ω. Estos valores son anormales, ya que entre dichas terminales no debe existir continuidad directa. Este comportamiento indica que ambos MOSFETs presentan un cortocircuito interno y se encuentran dañados.

1.1.d. MCU (LPC 1768)

Este microcontrolador es el “cerebro” de la placa. Se encarga de procesar toda la información proveniente de los sensores, ejecutar el firmware y coordinar las órdenes hacia los motores, termistores, MOSFETs, ventiladores y el resto de los módulos. Controla el movimiento, administra la temperatura y gestiona la comunicación USB/serial. Si su línea de alimentación se encuentra en corto o dañada, la placa pierde la capacidad de procesar instrucciones y deja de funcionar correctamente.

Se midió la línea de alimentación del microcontrolador (Lpc1768) y se encontró que entre VDD y GND había una lectura de aproximadamente 0,5–1,1 V en modo diodo, lo que indica que la línea está en corto o presenta una impedancia mucho menor a la esperada. Normalmente, entre VDD y GND no debe haber continuidad ni valores tan bajos, lo que sugiere que algún componente asociado a la alimentación del MCU también sufrió daños.

1.1.e. BUFFER HC125

Además, se detectó que el buffer HC125, ubicado en la misma región del circuito, también presentaba una falla. Este es un circuito integrado que funciona como driver y nivelador de señal. Su función principal es aislar, reforzar y estabilizar señales digitales entre el MCU y otros componentes de la placa. Permite que las señales se mantengan con el nivel adecuado de voltaje y evita que una falla en un sector afecte directamente al microcontrolador.

Las mediciones entre VCC y GND arrojaron un valor cercano a 6,6 Ω en modo diodo, lo cual es significativamente inferior a lo esperable en un circuito sano. Este valor confirma una pérdida de aislamiento interna y, por lo tanto, un daño en ese integrado.

### 1.2. Prueba de puenteado

Se realizó un puenteado para intentar restablecer la tensión y verificar el comportamiento del circuito. Sin embargo, el circuito entró en cortocircuito, lo cual indicó que la falla podría estar asociada a más de un componente y no únicamente al regulador. Este comportamiento también sugiere la posible existencia de pistas dañadas, cortos internos en algún componente SMD(tipo de componente que se suelda directamente sobre la superficie de la placa) o fallas en el integrado asociado al regulador.

Procedimos a sacar dicho componente y detectamos que es posible que el integrado asociado también haya resultado dañado.

### 1.3. Componentes que siguen funcionando

A pesar de esta falla, se comprobó que la zona de alimentación primaria, los diodos rectificadores, la entrada principal de alimentación y las líneas de suministro de bajo voltaje permanecieron en buen estado. Esta observación es crucial, ya que explica por qué algunos componentes seguían funcionando con normalidad: los fines de carrera, los ventiladores, los drivers de los motores, los sensores de temperatura (termistores) y otros módulos de bajo consumo continuaron funcionando perfectamente.

Esto es posible porque estos módulos trabajan con tensiones de 5 V y 3.3 V, reguladas por etapas independientes dentro de la placa. Como dichas etapas no fueron alcanzadas por la sobrecarga que afectó al circuito, lograron mantenerse estables y operativas. Por lo tanto, la placa mantenía su capacidad lógica y de control, aunque había perdido completamente la función de alimentar los elementos de alta demanda.

### 1.3. Componentes que no siguen funcionando

En cambio, los sistemas que requieren corrientes elevadas (como el cartucho calefactor del hotend y la cama caliente) no podían funcionar bajo ninguna circunstancia. Esto se debe a que ambos dependen directamente del regulador principal y del MOSFET Q2, que son los encargados de controlar y suministrar la energía necesaria para estos componentes.

2.Soluciones propuestas:

### 2.1. Reparación de la placa existente:

Esta opción consiste en reemplazar los componentes quemados.

Tiempo estimado:
2 a 4 días.

Ventajas: reparación económica.
Desventajas: la placa ya tiene daño estructural y puede perder confiabilidad a largo plazo.

2.1.a. Componentes a reemplazar:

- Regulador de tensión AMS 1117, 3.3V.

- MOSFET Q2 (WSK220N04).
- Posible integrado asociado a la etapa de regulación.

2.1.b.Costos estimados:

- Regulador de tensión: ARS 2.000 – 3.500
- MOSFET Q2 WSK220N04: ARS 7.000 – 10.500
- Mano de obra de microsoldadura: ARS 15.000 – 35.000
- Mosfet CDTO3N005: ARS 500-1500.
- Buffer HC125: ARS 1500-2500.
- MCU LPC 1768: ARS 60.000-70.000.

2.1.c.Links de compras:

- Regulador de tension: AMS 117, 3.3V (https://www.mercadolibre.com.ar/ams-1117-ams1117-ams1117-ams111733-regulador-33-v-1a/up/MLAU268859975)
- Transistor: Mosfet Q2 (https://www.mercadolibre.com.ar/wsk-220n04-wsk220n04-wsk220n04-mosfet-n-40v-220a-to263/up/MLAU212067033)
- Transistor 2: Mosfet CDTO3N005 (https://spanish.alibaba.com/product-detail/CTD03N005-CTD03N005-TO-252-MOSFET-diode-1600594655336.html)
- Buffer: BUFFER HC125 (https://www.mercadolibre.com.ar/74hc125-driver-cuadruple-no-inversor-dip14-itytarg/up/MLAU380591856)
- MCU LPC1768: LPC 1768 (https://www.mercadolibre.com.ar/microcontrolador-lpc1769-lpc1769fbd100-lpc1769fbd--1769/up/MLAU130498603)

### 2.2. Reemplazo completo de la placa controladora

En caso de que el daño sea extenso o afecte varias pistas internas, puede ser más conveniente reemplazar la placa completa.

Costo estimado: ARS 110.000 – 250.000 (dependiendo del modelo)

Tiempo estimado:
1–2 días (compra, montaje y pruebas).

Ventajas: solución estable y confiable; evita fallas futuras. Desventajas: mayor costo inicial.

2.2.a.Placas recomendadas y por qué

2.2.a.i. BTT SKR 1.4 Turbo

Motivos:

- Similar a la placa utilizada, por lo que se puede reemplazar la placa SKR 1,4 por esta sin tener que modificar casi nada en la impresora.
- Buena disipación térmica y compatibilidad con drivers TMC.
- Configuración sencilla en Marlin.

Esta placa es ideal porque mantiene exactamente la misma arquitectura y distribución de puertos que la placa SKR 1,4, evitando tener que cambiar cableado, conectores o firmware. Esto permite una recuperación rápida y con mínima intervención técnica. Es la opción más práctica ya que el objetivo es restaurar la impresora tal cual estaba antes de la falla.

Costo: ARS 215.00.

Link de compra: BTT SKR 1,4 TURBO (https://www.mercadolibre.com.ar/motherboard-btt-skr-v14-turbo-impresora-3d/up/MLAU202514396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)

2.2.a.ii. BTT SKR Mini E3 V3.0

Motivos:

- Drivers TMC integrados, silenciosos y eficientes.
- Mejoras de seguridad eléctrica.
- Sencilla de instalar y configurar.

Es ideal si se busca estabilidad y simplicidad porque integra los drivers directamente en la placa, reduciendo el riesgo de fallas por una conexión incorrecta, sobrecalentamiento o conexiones sueltas. Además, su electrónica está mejor protegida y su consumo es más eficiente, lo que la convierte en una opción confiable y silenciosa para uso continuo.

Costo: ARS 110.000

Link de compra: BTT SKR Mini E3 V3.0 (https://articulo.mercadolibre.com.ar/MLA-896428200-placa-bigtreetech-skr-mini-e3-v2-0-32b-tmc2209-ender-3-cr10-_JM)

2.2.a.iv. BTT SKR 2

Motivos:

- Mejor protección contra cortocircuitos.
- Regulación de energía más robusta.
- Diseñada para cargas elevadas (hotend y cama caliente).

Es ideal si se quiere evitar fallas similares en el futuro, ya que incluye protecciones reforzadas y un sistema de regulación de energía más estable. Esto reduce la probabilidad de que un pico de tensión o un cortocircuito vuelva a dañar la placa, siendo la opción más segura y duradera del listado.

Costo: ARS 120.000.

Link de compra :BTT SKR2 (https://www.mercadolibre.com.ar/motherboard-bigtreetech-btt-skr-2-impresora-3d-biqu-b1/up/MLAU145417933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)

3.Cómo se reemplazan los componentes:

### 3.1. Identificación del componente dañado

- Localizar el regulador, MOSFET Q2 y cualquier componente asociado.
- Verificar continuidad y medir caídas de tensión en la zona afectada.

### 3.2. Preparación de la zona

- Retirar restos de estaño o material quemado.

- Verificar que no haya pistas cortadas.

### 3.3. Retiro del componente

- Usar estación de aire caliente (no sirve el soldador ya que se necesita calentar todos los pines al mismo tiempo)
- Aplicar flux para evitar levantar pistas.
- Retirar suavemente el componente una vez fundido el estaño.

### 3.4. Colocación el componente nuevo

- Posicionar correctamente el regulador y el MOSFET.
- Soldar con aire caliente o punta fina, asegurando buena continuidad.
- Limpiar con alcohol isopropílico (para remover restos de flux, estaño quemado y suciedad).

### 3.5. Pruebas finales

- Verificar continuidad y ausencia de cortocircuitos.
- Conectar alimentación limitada (fuente con amperaje reducido).
- Confirmar que las líneas de 5 V, 3.3 V y 12/24 V estén estables.
- Probar endstops, ventiladores, drivers, USB.

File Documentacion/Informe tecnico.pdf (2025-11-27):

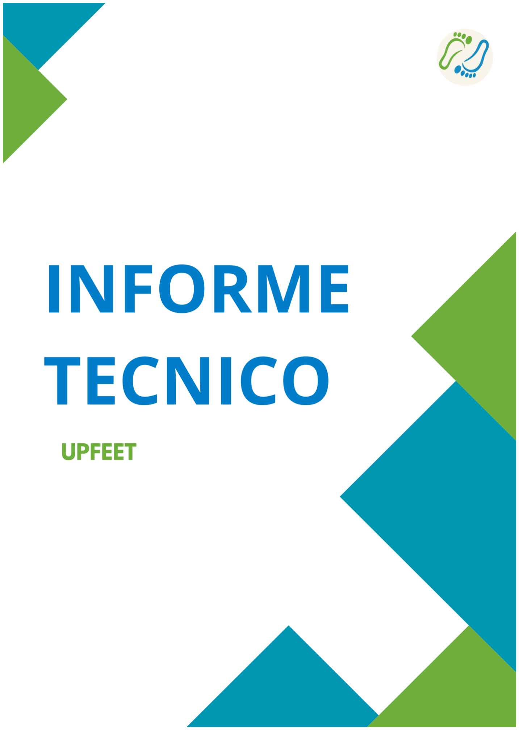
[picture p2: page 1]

# Indice

1. Introduccion | 2
a. Integrantes | 2
b. Esfuerzos | 2
c. Descripción General | 2
2. Escaner | 5
a. Estructura | 5
i. Materiales y componentes | 5
1. Estructura Principal | 5
2. Estructura de apoyo | 5
ii. Dimensiones | 6
1. Estructura Principal | 6
2. Estructura de apoyo | 7
iii. Planos | 8
1. Estructura Principal | 8
2. Estructura de apoyo | 9
b. Sistema de ejes | 9
i. Componentes | 9
ii. Planos de soportes caseros | 11
c. Placa Controladora | 12
i. Drivers | 12
ii. Raspberry pi 4 | 15
1. Codigo para drivers | 15
2. Codigo para sensor Lidar | 16
3. Código de procesamiento de datos | 17
4. Código para archivos | 18
iii. | Esquemático y PCB | 25
iv. | Alimentación | 26
1. Alimentación de los drivers | 26
2. Alimentación de la raspberry pi | 27
3. Justificación del diseño de alimentación | 28
d. Obstáculos encontrados y soluciones aplicadas | 28
i. Obstáculos estructurales | 28
ii. Obstáculos electrónicos | 29
e. Conclusiones | 30
i. Resultados técnicos alcanzados | 30
ii. Ideas a implementar en un futuro | 30
3. Impresora | 31
a. Estructura mecánica | 31
i. Estructura metálica | 31
ii. | Justificación de las dimensiones y disposición estructural | 32
iii. | Materiales utilizados y fundamentos de selección | 32
b. Sistema de ejes | 32
i. Configuración general de ejes (X, Y, Z) | 32
ii. | Componentes mecánicos de transmisión | 33
iii. | Medidas, relaciones de movimiento y guías lineales | 33

c. Electrónica de control | 34
i. Placa madre SKR V1.4 | 34
ii. | Distribución de pines (pinout general y específico) | 34.
iii. | Funcionamiento del sistema de control | 34
iv. | Implementación en la impresora desarrollada | 35
d. Limitaciones técnicas y soluciones aplicadas | 35
i. Problemas estructurales | 35
ii. | Problemas electrónicos | 36
iii. | Problemas de software | 36
e. Firmware | 37
i. Firmware base utilizado (Biqu / Marlin modificado) | 37
ii. | Configuración y personalización para la SKR V1.4 | 37
iii. | Cambios implementados en la versión final | 37
iv. | Resultados obtenidos tras la modificación | 37
f. Conclusiones | 37
i. Resultados técnicos alcanzados | 37
ii. Posibles mejoras futuras | 37

# 1.Introduccion

## 1.a. Integrantes

- Melina Alfonso
- Agustin Azorin
- Eugenio Herrera
- Tiago Lopez
- Victoria Viva
- Valentin Zaccari

## 1.b. Esfuerzos

Inicio de actividades:

- 20 de marzo 2025
- 35 semanas trabajadas
- 600 horas de trabajo total
- 17 horas aproximadas de trabajo por semana

## 1.c. Descripción general

El sistema UPFEET fue desarrollado como una solución tecnológica innovadora destinada a aliviar los dolores plantares y el cansancio físico del personal aeronáutico, en especial pilotos, tripulantes y técnicos que permanecen largas horas de pie o en posición estática dentro de la aeronave.

El proyecto integra un escáner plantar tridimensional con una impresora 3D Maker Pi Pro modificada, conformando una herramienta capaz de capturar, procesar y fabricar plantillas ortopédicas personalizadas de manera rápida, precisa y de bajo costo.

Objetivo principal

El objetivo de UPFEET es mejorar el confort postural y reducir las dolencias musculoesqueléticas del personal de vuelo mediante la digitalización exacta del pie y la fabricación directa de plantillas ortopédicas a medida.

El sistema busca brindar una alternativa más económica, portable y eficiente frente a los estudios ortopédicos tradicionales, los cuales suelen requerir equipos costosos, personal especializado y largos tiempos de análisis.
UPFEET, en cambio, permite realizar el escaneo, procesar los datos y obtener una plantilla personalizada en el mismo entorno de trabajo, optimizando recursos sin comprometer la precisión.

Así, el dispositivo contribuye a:

- Disminuir la fatiga y el dolor durante vuelos prolongados.
- Optimizar la postura corporal, reduciendo sobrecargas en tobillos, rodillas y columna.
- Democratizar el acceso a herramientas de corrección postural mediante un sistema simple, reproducible y de bajo costo.

Desarrollo y componentes principales

El sistema UPFEET se compone de dos módulos principales diseñados para funcionar de manera integrada:

1. Escáner plantar UPFEET:
- Captura la geometría del pie mediante un sensor LIDAR montado sobre un sistema de ejes motorizado con drivers TMC2208 y motores NEMA 17.
- Genera una matriz tridimensional de alturas que representa la superficie plantar con alta resolución.
- Los datos procesados se transforman en un archivo STL imprimible mediante código desarrollado específicamente para el proyecto.
2. Impresora 3D Maker Pi Pro modificada:
- Fue reacondicionada para adaptarse al proceso de fabricación de plantillas, con ajustes en firmware, volumen de impresión y calibración del extrusor.

- Permite imprimir directamente las plantillas ortopédicas generadas por el escáner, manteniendo la continuidad digital del proceso.
- Esta modificación formó parte integral del proyecto, asegurando compatibilidad entre hardware, software y materiales de impresión.

El conjunto constituye un ecosistema digital completo, capaz de escanear, procesar e imprimir soluciones personalizadas sin requerir equipos externos ni servicios adicionales.

Alcance del proyecto

Si bien el enfoque inicial se orienta al entorno aeronáutico, el sistema UPFEET posee un amplio potencial de expansión hacia otras áreas donde el confort postural y la salud laboral son esenciales:

- Salud y rehabilitación: creación de plantillas terapéuticas para fisioterapia y ortopedia.
- Deportes y alto rendimiento: análisis biomecánico y prevención de lesiones.
- Industria y logística: soporte ergonómico para trabajadores que permanecen de pie durante extensas jornadas.
- Calzado técnico y ortopédico: integración con procesos digitales de diseño y producción aditiva.

La arquitectura modular del sistema permite ajustar sus dimensiones, sensores y algoritmos según el uso final, manteniendo los principios de portabilidad, economía y accesibilidad que definen el proyecto.

Síntesis

UPFEET representa la convergencia entre biomecánica, manufactura digital y accesibilidad tecnológica.
Su desarrollo demuestra que es posible recrear el proceso de escaneo y fabricación ortopédica de forma compacta, económica y transportable, sin necesidad de un laboratorio especializado.
Gracias a la Maker Pi Pro modificada y al escáner plantar automatizado, el sistema logra reducir costos, tiempos y complejidad operativa, ofreciendo una alternativa viable para mejorar la salud postural del personal aeronáutico y de otros sectores que demanden ergonomía y confort prolongado.

# 2. Escaner

## 2.a. Estructura

2.a.i. Componentes y materiales

2.a.i.1. Estructura Principal

La estructura principal del sistema UPFEET está compuesta por una caja rectangular de acero fijada mediante 18 tornillos hexagonales distribuidos alrededor de los límites externos, 12 tornillos adicionales que aseguran la superficie transparente de acrílico de policarbonato, y 4 tornillos finales ubicados en las esquinas de los lados frontal y posterior para reforzar la rigidez general.

El material principal seleccionado fue acero debido a su alta resistencia mecánica, estabilidad dimensional y durabilidad ante esfuerzos repetitivos, especialmente considerando que la estructura soporta la presión del usuario al apoyar el pie.

Se optó por una geometría rectangular cerrada para favorecer la distribución homogénea de tensiones y simplificar la alineación del sistema óptico y electrónico, garantizando precisión en las mediciones.

El uso de tornillos hexagonales (en lugar de tornillos autorroscantes o cabezas ranuradas) responde a criterios de mantenimiento y modularidad:

- Permiten desmontar fácilmente las tapas o paneles para el mantenimiento interno sin deformar el material.
- Mejoran el par de apriete y reducen el riesgo de dañar las cabezas con herramientas comunes.
- Favorecen una apariencia profesional y robusta, coherente con el estándar de equipamiento médico-técnico que busca proyectar el sistema UPFEET.

Asimismo, el acrílico de policarbonato transparente se eligió por su alta resistencia al impacto y excelente transmisión lumínica, permitiendo la correcta lectura del escáner 3D sin interferencias ópticas ni riesgo de rotura ante uso intensivo. Otras alternativas como el vidrio o metacrilato fueron descartadas: el primero por su peso y fragilidad, y el segundo por su menor resistencia térmica.

En síntesis, esta configuración logra el equilibrio entre rigidez estructural, facilidad de mantenimiento y precisión del sistema óptico, tres condiciones indispensables para el funcionamiento confiable y seguro del equipo.

2.a.i.2. Estructura de Apoyo

La estructura de apoyo también está fabricada en acero, pero presenta una forma en “U” cuadrada, diseñada específicamente para encastrarse y sostener firmemente a la estructura principal. Esta elección responde a criterios tanto funcionales como ergonómicos:

- La forma en “U” permite una fijación estable y autoalineada, evitando desplazamientos laterales del conjunto durante el transporte.
- Facilita el montaje y desmontaje rápido del sistema, útil para el traslado.
- Proporciona una superficie de apoyo estable para el pie del usuario, evitando cargas innecesarias sobre la estructura principal y mejorando la estabilidad postural durante el escaneo.

Se mantuvo la coherencia de materiales (acero) para garantizar una compatibilidad térmica y mecánica entre ambas estructuras, evitando deformaciones diferenciales por cambios de temperatura o humedad. Además, se descartaron materiales alternativos como aluminio o plástico reforzado, ya que:

- El aluminio, aunque más liviano, presenta menor rigidez frente a torsiones repetitivas y puede deformarse con el tiempo.
- Los plásticos estructurales, por su parte, no ofrecen la misma estabilidad dimensional ni resistencia al impacto que requiere un entorno técnico de laboratorio o consultorio.

### 2.a.ii. Dimensiones

2.a.ii.1. Estructura Principal

La estructura principal del sistema UPFEET presenta unas dimensiones generales de 500 × 300 × 300 mm, configurando un volumen compacto que permite alojar los componentes ópticos, electrónicos y mecánicos del escáner sin comprometer la estabilidad del conjunto.

En su parte superior, la superficie transparente de acrílico de policarbonato mide 300 × 150 × 10 mm, dimensiones que fueron seleccionadas de forma estratégica:

- El largo y ancho superan levemente las medidas promedio del pie humano (entre 260 y 280 mm de largo y 100 a 110 mm de ancho), lo que garantiza una superficie de apoyo cómoda y segura para usuarios de distintos tamaños.
- El espesor de 10 mm ofrece rigidez suficiente para resistir el peso del usuario sin flexión visible ni deformaciones ópticas que pudieran afectar la calidad del escaneo.
- Esta proporción permite, además, mantener un campo visual completo del sensor 3D, optimizando el enfoque y la precisión de captura.

En conjunto, las dimensiones fueron determinadas para lograr el equilibrio entre ergonomía, precisión de escaneo y facilidad de transporte, manteniendo el peso total del sistema dentro de límites razonables para su manipulación manual.

2.a.ii.2. Estructura de Apoyo

La estructura de apoyo fue diseñada con dimensiones ligeramente superiores a las de la estructura principal, permitiendo un encastre preciso y estable entre ambas piezas. Esta diferencia dimensional garantiza:

- Un ajuste firme, que evita holguras o movimientos durante el uso.
- Una correcta distribución de cargas, reduciendo el esfuerzo sobre los tornillos de fijación.
- Un montaje simple y repetible, que facilita la alineación automática del escáner respecto al plano del suelo.

El sobredimensionado se limita a unos pocos milímetros por lado, suficiente para asegurar el acople funcional sin interferencias y manteniendo la estética compacta del equipo.

De esta manera, las dimensiones conjuntas de ambas estructuras responden tanto a criterios ergonómicos (comodidad del usuario) como a criterios de ingeniería (estabilidad, modularidad y resistencia), garantizando la integridad física del escáner y la exactitud en sus mediciones tridimensionales.

2.b.i. Componentes

El sistema de ejes del escáner UPFEET está conformado por tres ejes lineales que permiten el desplazamiento controlado del sensor de medición: dos ejes Z y un eje X.

Los dos ejes Z son los responsables de mover el eje X en sentido longitudinal (adelante y atrás), mientras que el eje X desplaza el sensor LIDAR de derecha a izquierda, cubriendo así toda la superficie de escaneo.
Esta disposición de ejes fue seleccionada por su estabilidad, precisión y simplicidad mecánica, además de permitir un mantenimiento más accesible que otras configuraciones como el sistema cartesiano clásico con eje Y independiente o el pórtico invertido.

Configuración de motores y acoples

Cada eje está accionado por un motor paso a paso independiente, garantizando movimientos precisos y sincronizados.

- Los motores de los ejes Z están atornillados a las paredes internas traseras de la estructura principal, lo que proporciona un anclaje rígido y reduce la transmisión de vibraciones al resto del chasis.
- El motor del eje X se encuentra sostenido por un soporte impreso en 3D, diseñado a medida, que se fija a la varilla de uno de los ejes Z. Esta solución “casera” permite ajustar la posición del motor con alta flexibilidad, adaptándose al recorrido real del sensor sin necesidad de mecanizados complejos en el bastidor.

Cada motor se acopla a su respectiva varilla mediante un acople flexible de 5 mm a 8 mm, que conecta el eje del motor con la varilla roscada de acero inoxidable de 8 mm de diámetro.
La elección de acoples flexibles se justifica porque:
- Absorben ligeras desalineaciones entre el motor y la varilla, evitando esfuerzos radiales que podrían dañar los rodamientos.
- Reducen vibraciones y prolongan la vida útil de los componentes.
- Facilitan el mantenimiento, ya que se pueden desmontar sin desajustar toda la transmisión.

Varillas y soportes estructurales

Cada varilla roscada (en acero inoxidable) está acompañada por dos varillas lisas de guía, también de acero, que garantizan la rectitud del movimiento y la estabilidad del eje móvil.

En los ejes Z, las varillas roscadas se sostienen mediante soportes frontales atornillados a la pared interna de la estructura principal, lo que evita que el peso del eje X provoque flexión o caídas durante la operación.
En el eje X, las varillas lisas están unidas a un soporte móvil que se apoya sobre una de las varillas roscadas del eje Z, logrando así una interconexión mecánica sólida y sincronizada entre los ejes.

Cada soporte móvil incorpora una tuerca antibacklash, lo que compensa el juego mecánico entre la rosca y la varilla, garantizando:

- Mayor precisión en el desplazamiento del sensor LIDAR.
- Ausencia de vibraciones en el sentido inverso de movimiento.
- Repetibilidad de posición, fundamental para obtener nubes de puntos limpias y sin errores de registro.

Justificación del diseño del sistema de ejes

Se optó por este sistema de tres ejes con motores independientes por las siguientes razones:

1. Precisión y repetibilidad: permite controlar con exactitud la posición del sensor, condición esencial para reconstrucciones tridimensionales de alta fidelidad.
2. Simplicidad constructiva: elimina la necesidad de mecanismos de transmisión por correas o engranajes, reduciendo el mantenimiento y los puntos de falla.
3. Modularidad y reparación accesible: los componentes (varillas, tuercas, acoples, soportes) son estándar y fáciles de reemplazar, lo cual facilita las tareas de ajuste o actualización.
4. Compatibilidad con impresión 3D: el uso de soportes impresos a medida permite adaptar el diseño a variaciones dimensionales y optimizar el espacio interno del escáner sin requerir mecanizado industrial.

### 2.b.ii. Planos de Soportes caseros

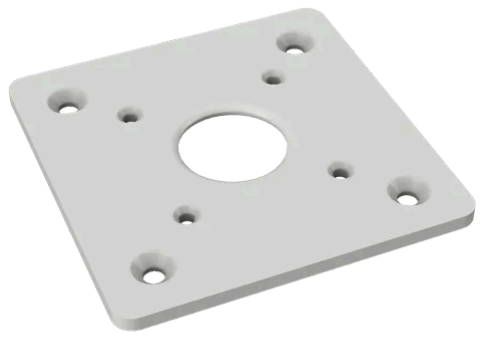
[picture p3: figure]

## 2.c. Placa Controladora

2.c.i. Drivers

El sistema UPFEET utiliza drivers TMC2208 para el control de los motores paso a paso de los ejes X y Z. Estos módulos se encargan de traducir las señales digitales de la placa controladora en impulsos eléctricos precisos, regulando la corriente que llega a cada bobina del motor. De este modo, permiten un movimiento suave, silencioso y exacto del sistema de ejes.

Principio de funcionamiento electrónico

El TMC2208 funciona como un controlador de micropasos (hasta 1/256 de paso) que emplea una tecnología denominada StealthChop, capaz de generar una corriente sinusoidal extremadamente estable.
Esto reduce el ruido electromecánico típico de los motores paso a paso convencionales, eliminando vibraciones y mejorando la precisión del posicionamiento.

En el esquema mostrado (ver figura), se observan las principales conexiones del driver:

- VM (Voltaje de motor): alimentación principal de los motores, 12V
- VIO: alimentación lógica, conectada a 3.3 V desde la placa controladora.
- M1A / M1B / M2A / M2B: salidas hacia las dos bobinas del motor paso a paso.
- STEP / DIR: señales digitales provenientes del microcontrolador, que determinan los impulsos de paso y el sentido de giro.
- EN: señal de habilitación, utilizada para activar o desactivar el driver, siempre en 0 para que esté activado el driver.
- PDN_UART: interfaz de comunicación que permite configurar parámetros avanzados como corriente, microstepping o modo de funcionamiento.
- VREF: pin de referencia de voltaje, utilizado para ajustar la corriente máxima que circulará por las bobinas del motor.

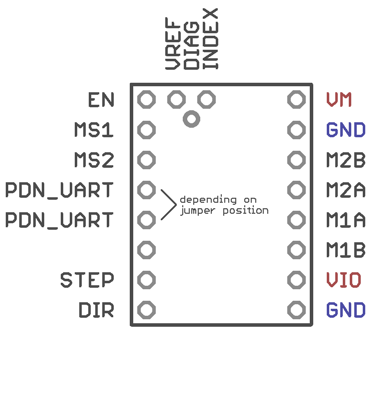
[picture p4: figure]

Por qué no utilizamos los pines MS1 y MS2 del driver TMC2208

Los pines MS1 y MS2 en los controladores de motores paso a paso tradicionalmente se utilizan para definir el modo de micropasos del motor.
En drivers más antiguos, como el A4988 o el DRV8825, estos pines se conectaban a niveles lógicos fijos (HIGH o LOW) para seleccionar entre 1, ½, ¼, ⅛, 1/16 o 1/32 de paso, configurando así la resolución mecánica del motor.

Sin embargo, en el caso del TMC2208, esos pines ya no se utilizan para configurar el microstepping.
Este modelo de driver incorpora un sistema de control interno digital más avanzado, lo que hace que la configuración de micropasos se realice automáticamente o mediante software, no por hardware.

En el TMC2208, el número de micropasos se puede definir de tres maneras:

1. Por comunicación UART: el firmware (por ejemplo, Marlin o el código en Raspberry Pi) envía comandos digitales para configurar la resolución.
2. Por resistencias internas preconfiguradas: cuando no se usa UART, el driver arranca por defecto en 1/16 de paso con interpolación a 1/256, lo que da movimientos ultrasuaves.
3. Por pins CFG (según versión): en algunas placas, los pines CFG1 y CFG2 reemplazan a MS1/MS2, pero se dejan desconectados o a GND para usar la configuración por defecto.

En el proyecto UPFEET, no se utilizaron los pines MS1 y MS2 porque:

- No son necesarios para el control del microstepping en el TMC2208.
El driver ya cuenta con interpolación interna StealthChop que convierte automáticamente los micropasos a 1/256 sin necesidad de configuración externa.
- Simplifica el cableado.
Evitar el uso de esos pines reduce la cantidad de conexiones entre la Raspberry Pi y los drivers, disminuyendo posibles interferencias o errores de montaje.
- Compatibilidad con el firmware.
Al usar la configuración por defecto, el sistema puede comunicarse con los drivers sin requerir comandos UART adicionales ni librerías de configuración, lo que se adapta mejor a un entorno de desarrollo experimental y estable.
- Estabilidad en el movimiento.
El modo interpolado del TMC2208 ofrece movimientos suaves, silenciosos y precisos, ideales para el escáner 3D del sistema UPFEET, sin necesidad de modificar manualmente la resolución.

Ventajas de no usar MS1/MS2

- Menor complejidad eléctrica: menos cables y menor riesgo de cortocircuitos o errores de pinout.
- Funcionamiento automático y silencioso: el TMC2208 gestiona la corriente y los micropasos internamente mediante el algoritmo StealthChop.
- Compatibilidad con código genérico: el driver funciona correctamente con los mismos comandos básicos (STEP y DIR) que un A4988, sin necesidad de configuración adicional.
- Mayor precisión efectiva: aunque se trabaja en 1/16 de paso, el driver interpola digitalmente hasta 1/256, logrando movimientos más finos que los configurables por hardware.

Ajuste del voltaje de referencia (Vref)

El Vref se utiliza para establecer la corriente máxima que suministrará el driver al motor. En el caso de los motores NEMA 17 genéricos, típicos en aplicaciones de escaneo o impresión 3D, la corriente nominal suele ser de 1 A a 1.2 A por fase.

La corriente máxima se calcula según la fórmula aproximada del TMC2208:

Donde | suele ser de 0.11 Ω en los módulos más comunes.
Para obtener una corriente de 1 A:

En la práctica, se recomienda ajustar el Vref entre 0.18 V y 0.22 V, lo cual:

- Evita sobrecalentamientos del motor o del driver.
- Proporciona suficiente torque para mover el sistema sin pérdida de pasos.
- Extiende la vida útil del motor y reduce el ruido operativo.

Este rango fue validado experimentalmente en el sistema UPFEET, donde se busca movimiento suave y preciso, priorizando la estabilidad del escaneo sobre la velocidad máxima.

Ventajas y desventajas del TMC2208

Ventajas:

- Funcionamiento ultrasilencioso (StealthChop): ideal para entornos clínicos o de laboratorio donde se requiere bajo nivel de ruido.
- Alta resolución de microstepping (hasta 1/256): mejora la precisión de posicionamiento del sensor LIDAR.
- Protección térmica y de sobrecorriente integrada.
- Compatibilidad directa con drivers A4988 o DRV8825, facilitando el reemplazo.
- Configuración por UART: permite ajustar corriente, pasos y modos de trabajo sin modificar hardware.

Desventajas:

- Requiere una correcta ventilación si se trabaja a corrientes elevadas.
- Menor torque a bajas velocidades en comparación con el DRV8825, si no se calibra el Vref adecuadamente.

- Configuración UART opcional puede complicar la instalación si no se dispone de firmware compatible.

Justificación de elección

El TMC2208 fue seleccionado como driver principal del sistema UPFEET por las siguientes razones:

1. Compatibilidad directa: se adapta perfectamente a la topología de la placa controladora utilizada, sin necesidad de rediseñar el sistema eléctrico.
2. Rendimiento acústico: la tecnología StealthChop reduce significativamente el ruido mecánico del escáner, aportando una experiencia más profesional.
3. Costo-beneficio: ofrece prestaciones similares a modelos más avanzados (como el TMC2209 o TMC2130) a un precio considerablemente menor.
4. Disponibilidad: eran los mismos drivers utilizados por la impresora 3D del laboratorio, por lo que se aprovecharon unidades existentes, evitando costos de envío adicionales y garantizando compatibilidad de repuestos.
5. Mantenimiento sencillo: el ajuste de Vref es accesible y los parámetros son fácilmente replicables en caso de sustitución.

(La figura a continuación muestra el pinout de conexión del TMC2208 utilizado en el sistema UPFEET.)

### 2.c.ii. Raspberry pi

La Raspberry Pi 4 actúa como el cerebro principal del sistema UPFEET, coordinando el control de los motores, la adquisición de datos del sensor LIDAR, el procesamiento de la información tridimensional y el almacenamiento de los resultados.
A continuación, se describen las principales secciones de código utilizadas en el sistema.

2.c.ii.1. Codigo para drivers
Este código se encarga de enviar las señales de paso (STEP) y dirección (DIR) a los drivers TMC2208 que controlan los motores NEMA 17.
Permite realizar movimientos precisos y sincronizados en los ejes X y Z.

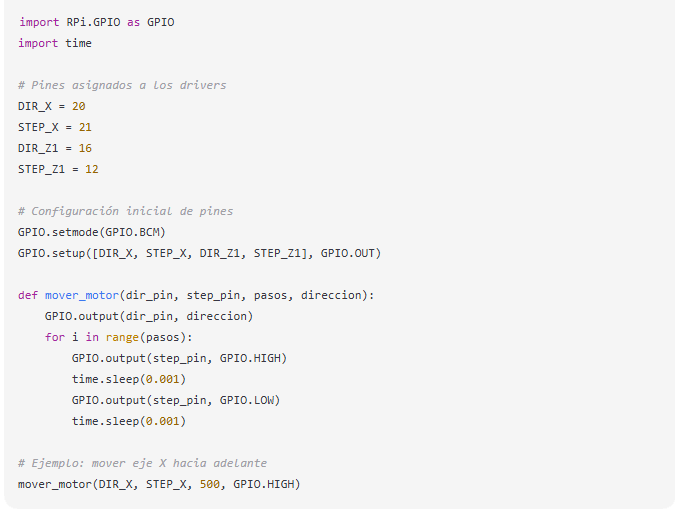
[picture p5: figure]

Explicación:
El programa genera pulsos digitales que determinan la rotación de cada motor.
El número de pasos y la dirección son ajustables, permitiendo calibrar la velocidad y distancia de desplazamiento del sensor.

2.c.ii.2. Codigo para LIDAR
Este bloque se comunica con el sensor LIDAR para leer las distancias medidas.
Utiliza una interfaz UART (o I2C, dependiendo del modelo), procesando los datos de forma continua mientras el sensor se desplaza.

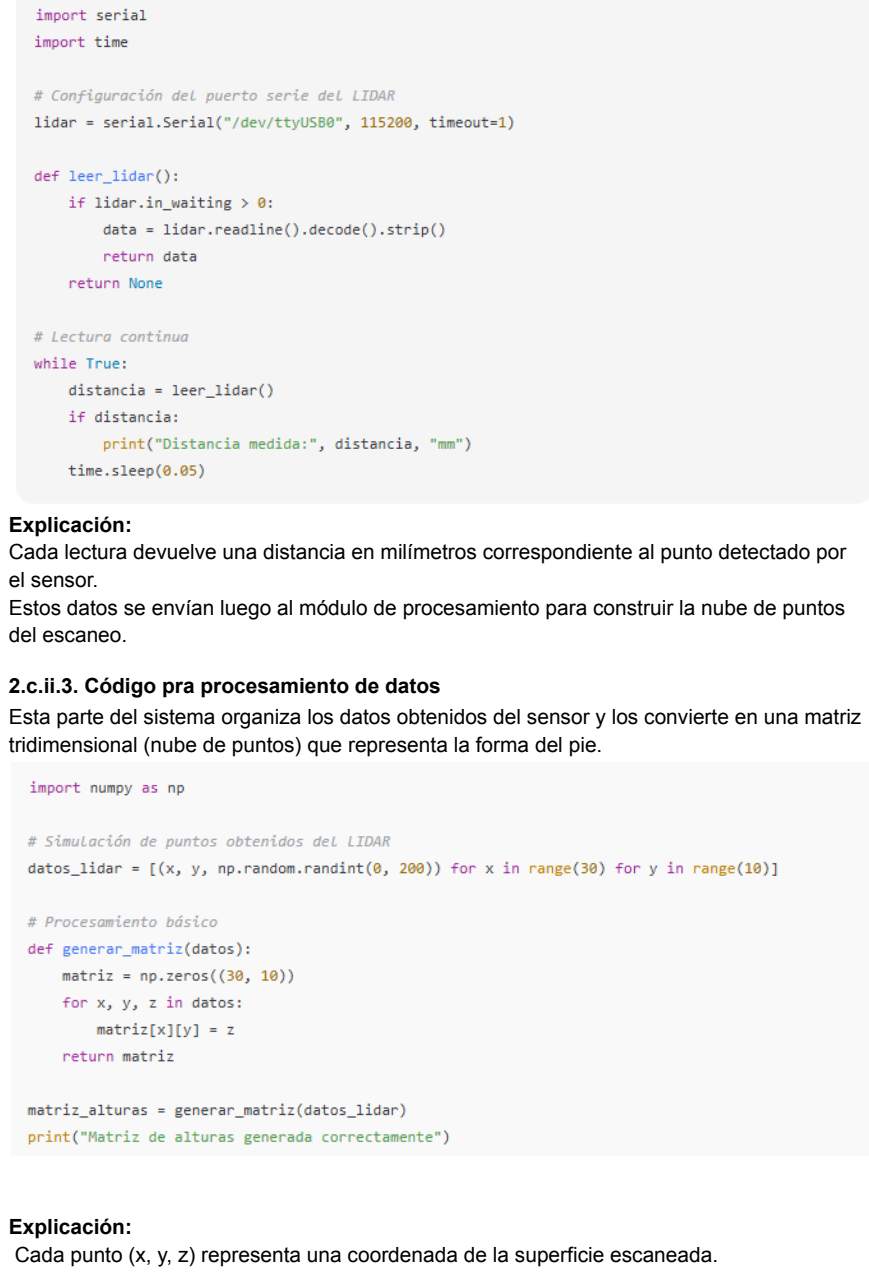
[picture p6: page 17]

Explicación:
Cada lectura devuelve una distancia en milímetros correspondiente al punto detectado por el sensor.
Estos datos se envían luego al módulo de procesamiento para construir la nube de puntos del escaneo.

2.c.ii.3. Código pra procesamiento de datos
Esta parte del sistema organiza los datos obtenidos del sensor y los convierte en una matriz tridimensional (nube de puntos) que representa la forma del pie.

Explicación:
Cada punto (x, y, z) representa una coordenada de la superficie escaneada.

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
s, e

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
a la im

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
e la plantilla.

2.c.ii.4. Código para archivos

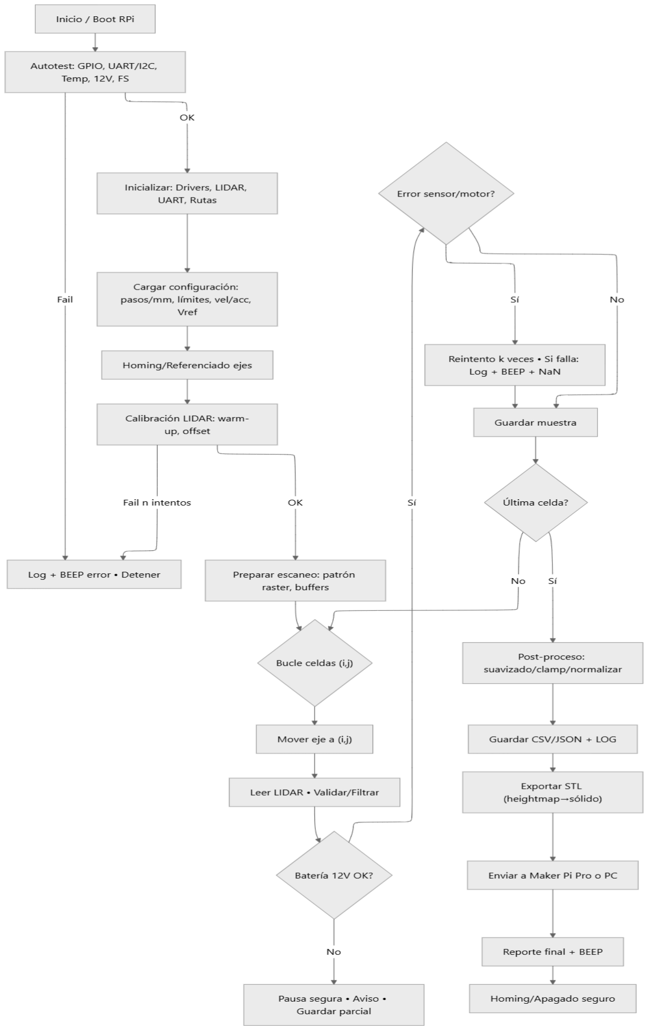
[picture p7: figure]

Explicación detallada de los bloques del flujo de procesos

### 1. Inicio / Boot de la Raspberry Pi

Al encender el sistema, la Raspberry Pi ejecuta su secuencia de arranque y carga el entorno operativo.
Se inicia el servicio principal del escáner (por ejemplo, un script Python o un daemon) que coordina los motores, sensores y registros de datos.
El software verifica la integridad de los archivos de configuración y la disponibilidad del sistema de archivos.

### 2. Autotest del sistema

Antes de habilitar cualquier movimiento, el sistema ejecuta un autodiagnóstico:

- Comprueba la conectividad de los puertos GPIO, UART y I²C.
- Verifica el voltaje de alimentación de 12 V para los drivers y la disponibilidad de la fuente de 5 V.
- Controla la temperatura de la CPU y el estado de las pilas/baterías.
- Si detecta alguna anomalía, registra el evento en un archivo de log y emite un código acústico (beep) correspondiente.

Esto previene que el escáner inicie con una falla eléctrica o térmica.

### 3. Inicialización de periféricos

Una vez completado el autotest, la Raspberry Pi inicializa:

- Los drivers TMC2208 (habilita pines STEP/DIR y señales ENABLE).
- El sensor LIDAR (establece comunicación UART y velocidad en baudios).
- El reloj interno o temporizador de muestreo.
- Las rutas de guardado para los datos del escaneo.

En esta etapa también se limpia la memoria de buffer y se prepara el espacio para la matriz de alturas.

### 4. Carga de configuración

Se leen los parámetros almacenados en un archivo de configuración, entre ellos:

- Pasos por milímetro (relación del motor con el desplazamiento real).
- Límites de recorrido de los ejes.
- Velocidades de desplazamiento y aceleraciones permitidas.
- Valor de Vref objetivo (corriente máxima de los motores).
Esto garantiza que el escáner trabaje bajo los mismos parámetros en cada sesión.

### 5. Homing / Referenciado

El sistema realiza un movimiento controlado hasta los puntos de referencia de los ejes (inicio físico o virtual).
Esto permite definir el punto (0, 0, 0) del sistema de coordenadas y evitar choques mecánicos.
Si se detectan finales de carrera, se detiene automáticamente.
El resultado del homing se almacena para sincronizar el movimiento posterior.

### 6. Calibración del sensor LIDAR

El sensor realiza una fase de estabilización (warm-up) y se calibra la distancia cero:

- Se toman varias lecturas con el sensor apuntando a una superficie plana conocida.
- Se calcula un promedio y se guarda un offset de corrección.
- Si la variabilidad de los datos es alta, se repite la calibración hasta obtener estabilidad.

Si después de varios intentos la calibración falla, se registra el error y el sistema no continúa hasta resolverlo.

### 7. Preparación del escaneo

El software define el patrón de movimiento (raster o serpenteado) y crea los buffers de almacenamiento para las lecturas.
Se establecen las dimensiones de la grilla (por ejemplo, 60 × 30 puntos) y el orden de desplazamiento de los ejes X y Z.

También se activan los indicadores visuales o sonoros que confirman que el sistema está listo para iniciar el escaneo.

### 8. Bucle de escaneo

Esta es la parte central del proceso:

1. El eje Z mueve el sensor a la posición correspondiente a la fila actual.
2. El eje X se desplaza paso a paso, y en cada posición el LIDAR realiza una lectura.
3. El valor de distancia medido se almacena en la matriz junto con sus coordenadas (x, y, z).
4. Se aplica una validación (verifica que la lectura sea numérica y esté dentro del rango útil).
5. Si alguna muestra falla, se repite la medición o se marca como NaN (no válida).

Durante el proceso:

- Si el voltaje de 12 V desciende, el escaneo se pausa automáticamente, guarda el progreso y emite un aviso acústico.
- Si ocurre un error de comunicación o motor, intenta un reintento local antes de abortar.

### 9. Post-proceso

Cuando finaliza el recorrido completo:

- Se aplica un filtro de suavizado (por ejemplo, media 3×3) para reducir ruido.
- Se normalizan las alturas (ajuste de escala y eliminación de valores anómalos).
- Se convierte la matriz a milímetros reales según la calibración previa.

El resultado es una matriz tridimensional precisa del perfil plantar.

### 10. Guardado de datos (CSV / JSON)

El sistema genera archivos de respaldo:

- CSV o JSON con todas las lecturas del escaneo.
- Archivo de log con hora, fecha, duración, temperatura y errores detectados. Estos archivos permiten repetir el análisis sin tener que volver a escanear.

### 11. Exportación a STL

Usando el algoritmo de triangulación, la matriz procesada se transforma en un sólido 3D (STL ASCII).
El modelo incluye la superficie plantar, la base inferior y las paredes laterales, asegurando que sea manifold (cerrado) y apto para impresión 3D.
La Raspberry Pi crea el archivo y lo deja listo para la siguiente etapa.

### 12. Envío a la Maker Pi Pro

El archivo STL se envía a la Maker Pi Pro modificada (ya sea por USB o red local).
La impresora inicia la fabricación de la plantilla ortopédica personalizada directamente desde el modelo obtenido.
En esta etapa puede verificarse la temperatura del hotend y la cama antes de imprimir.

### 13. Reporte final y señal acústica (BEEP)

Una vez completado el proceso, el sistema emite un código sonoro para indicar el estado final:

- 1 beep corto → Proceso exitoso.
- 2 beeps cortos → Advertencia o lectura parcial.
- 3 beeps cortos → Error crítico.
También se genera un resumen de resultados (tiempo total, lecturas válidas, archivo STL generado).

### 14. Homing final y apagado seguro

Finalmente, los ejes regresan a la posición de reposo y se deshabilitan los motores para reducir consumo.
El sistema cierra los puertos UART y GPIO, guarda el log final y apaga la Raspberry Pi de forma segura.
El escáner queda listo para el próximo uso.

### 2.c.iii. Esquematico y PCB

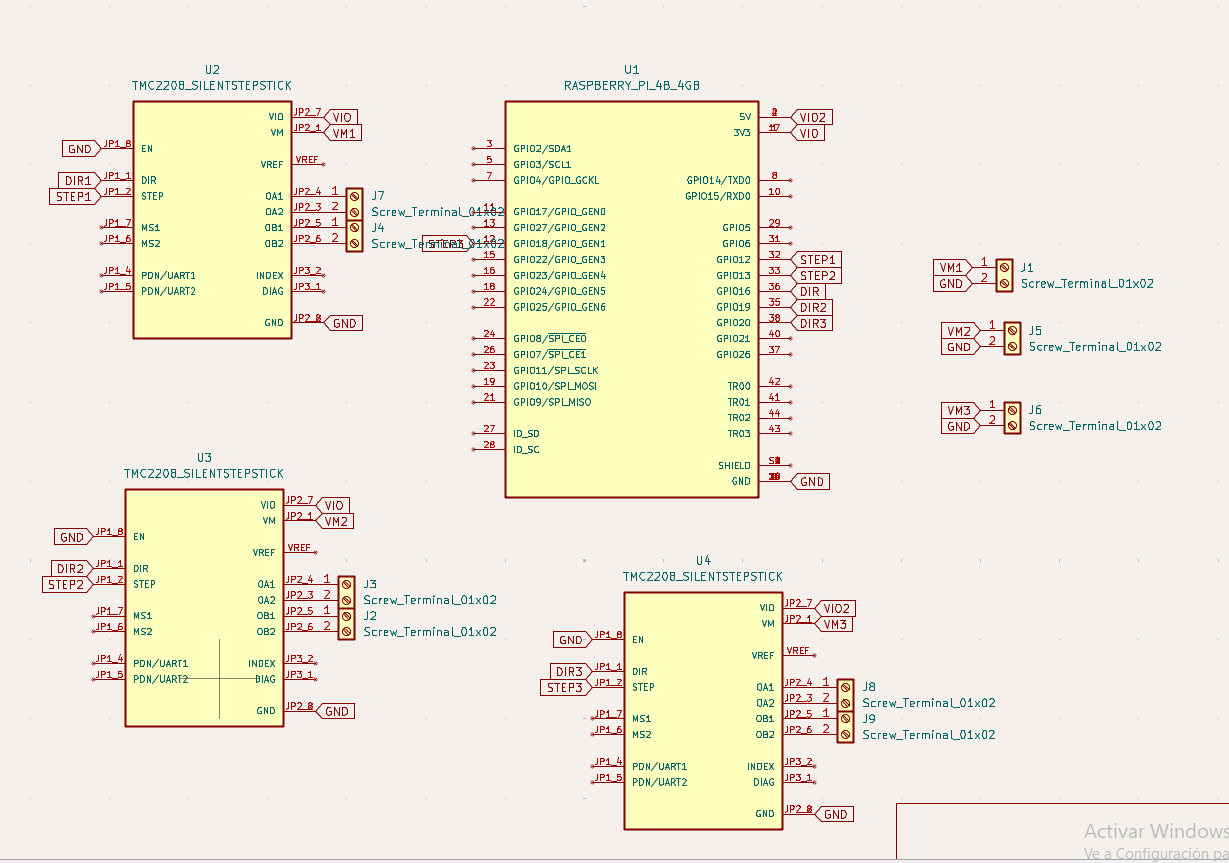
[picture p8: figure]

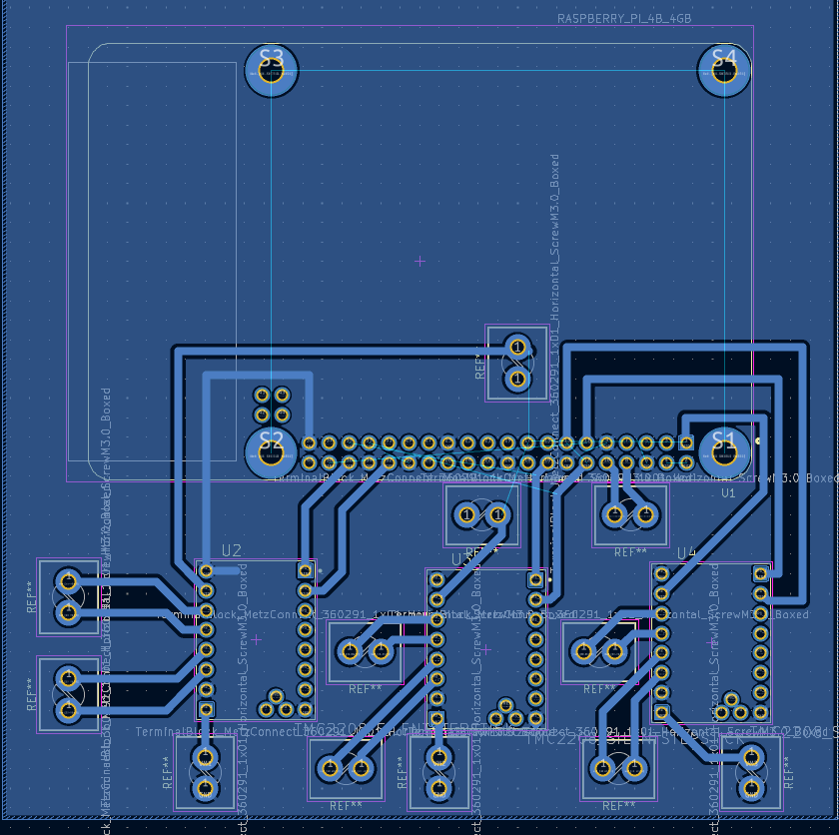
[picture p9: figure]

### 2.c.iv. Alimentacion

El sistema UPFEET requiere dos fuentes de alimentación diferenciadas para garantizar un funcionamiento estable y seguro de todos sus componentes electrónicos:

- Una fuente de 12 V destinada a los drivers(TMC2208).
- Una fuente de 5 V dedicada a la Raspberry Pi

2.c.ii.1. Alimentación de los drivers

La alimentación de 12 V se obtiene mediante un banco de pilas AA conectadas en paralelo, lo que permite aumentar la corriente total disponible manteniendo el mismo nivel de tensión nominal.

Cada pila AA entrega aproximadamente 1,5 V, por lo que se emplea un arreglo previo en serie de 8 unidades (1,5 V × 8 = 12 V) para alcanzar el voltaje requerido, y luego se replica este conjunto en paralelo para multiplicar la capacidad de corriente (mAh) y así alimentar simultáneamente los tres motores NEMA 17 controlados por los drivers TMC2208.

Esta configuración fue elegida por los siguientes motivos:

- Autonomía y portabilidad: permite operar el sistema sin depender de una fuente externa o toma de corriente, facilitando pruebas y calibraciones fuera del entorno de laboratorio.
- Seguridad eléctrica: las pilas ofrecen una corriente limitada, reduciendo el riesgo de sobrecorriente o cortocircuitos que pudieran dañar los drivers.
- Simplicidad de implementación: evita la necesidad de fuentes conmutadas o reguladores adicionales, simplificando el cableado interno.
- Compatibilidad: los TMC2208 admiten un rango de operación entre 5,5 V y 36 V, por lo que 12 V representa un punto de equilibrio ideal entre torque, eficiencia y bajo nivel de ruido.

Sin embargo, se consideraron también las limitaciones inherentes a este tipo de alimentación:

- La capacidad total de corriente depende del número de conjuntos en paralelo, por lo que una autonomía prolongada requiere más grupos de pilas.
- Las pilas alcalinas pueden presentar caídas de tensión en uso prolongado, afectando el rendimiento de los motores si no se reemplazan periódicamente.
- A pesar de ello, la solución resultó económica, segura y fácilmente reemplazable, adecuada para el prototipo funcional del sistema.

2.c.ii.2. Alimentación de la Raspberry Pi

La Raspberry Pi se alimenta mediante su cargador oficial de 5 V / 3 A, conectado directamente al puerto USB-C del dispositivo.

Esta fuente fue seleccionada por las siguientes razones:

- Estabilidad eléctrica garantizada: el cargador oficial incluye regulación precisa de tensión, evitando caídas de voltaje que podrían causar reinicios o errores de lectura en los periféricos USB o GPIO.
- Protección integrada: cuenta con sistemas de protección contra sobrecorriente y cortocircuitos.

- Compatibilidad directa: elimina la necesidad de adaptadores o convertidores adicionales, asegurando una integración limpia con la electrónica general del sistema.

La separación física y eléctrica entre la alimentación de la Raspberry Pi y la de los motores evita ruidos eléctricos y picos de corriente que podrían interferir en las comunicaciones con el sensor LIDAR o en el control de los drivers.

2.c.ii.3. Justificación del diseño de alimentación

El diseño mixto —baterías para la sección de potencia y cargador dedicado para la sección lógica— fue adoptado para equilibrar autonomía, seguridad y modularidad, cumpliendo con los siguientes criterios:

1. Independencia de circuitos: el sistema de potencia y el sistema lógico se encuentran eléctricamente aislados, evitando interferencias cruzadas.
2. Facilidad de mantenimiento: ambos sistemas pueden desconectarse o reemplazarse de forma independiente sin afectar la integridad del circuito principal.
3. Costo y disponibilidad: se aprovecharon recursos accesibles (pilas y cargador original), reduciendo costos de fabricación y logística.
4. Escalabilidad: la fuente de 12 V puede ser reemplazada en el futuro por una batería recargable Li-ion o una fuente regulada, sin alterar la topología general del circuito.

## 2.d. Obstáculos encontrados y Soluciones aplicadas

### 2.d.i. Obstáculos Estructurales

Durante el desarrollo del sistema UPFEET se presentaron diversos desafíos vinculados a la fabricación y ensamblaje de la estructura mecánica, principalmente asociados a limitaciones de recursos, disponibilidad de materiales y adaptación de componentes.

En primer lugar, si bien el diseño estructural se encontraba definido y modelado correctamente, el costo y nivel de conocimiento técnico necesarios para su construcción superaban nuestras posibilidades de fabricación directa.
El trabajo requería equipos de soldadura, mecanizado y corte de precisión, además de materiales metálicos específicos.
Frente a esta dificultad, se logró establecer un vínculo con la empresa Metalurgia Cronos, que patrocinó el proyecto y se encargó de fabricar la estructura principal y de apoyo según nuestras especificaciones técnicas.
Este apoyo externo fue fundamental para avanzar con el prototipo manteniendo los estándares de calidad y precisión requeridos.

En segundo lugar, se detectó la imposibilidad de conseguir tuercas antibacklash en el mercado local del Gran Buenos Aires, y las opciones disponibles en línea presentaban costos de envío excesivos.
Ante esta situación, se decidió fabricar las tuercas antibacklash manualmente, utilizando materiales disponibles en el laboratorio y aplicando un sistema de resorte de compresión ajustado.
Si bien este procedimiento demandó pruebas iterativas, permitió obtener un resultado funcional y estable, resolviendo el problema sin incrementar el presupuesto.

Finalmente, durante las pruebas de ensamblaje del sistema de ejes, se detectó que los acoples flexibles utilizados para conectar los motores a las varillas roscadas provocaban un desplazamiento mínimo en el recorrido total del eje X.
Como consecuencia, el sensor LIDAR no alcanzaba a escanear completamente un extremo de la superficie transparente, dejando una zona sin digitalizar.
Para corregir este inconveniente, se diseñó y montó un soporte auxiliar en forma de “L”, impreso en 3D, que permitió retrasar el sensor unos centímetros y recuperar el área completa de escaneo.
Esta solución, aunque sencilla, mejoró significativamente la cobertura del sistema y demostró la capacidad de adaptación del equipo ante problemas de montaje real.

### 2.d.ii. Obstáculos electrónicos

Durante el desarrollo del sistema electrónico del escáner UPFEET se presentaron diversos inconvenientes relacionados con la conectividad de los componentes, la estabilidad del sistema de control y las limitaciones de hardware disponibles.

El primer desafío se presentó con el sensor LIDAR, cuyo cableado original resultó insuficiente para permitir el desplazamiento completo a lo largo del eje de escaneo.
Dado que el recorrido del sensor requería una extensión mayor, se procedió a aumentar el alcance de los cables mediante extensiones Dupont, asegurando la continuidad eléctrica mediante cinta aislante de protección para evitar falsos contactos o desconexiones durante el movimiento.
Esta solución, aunque sencilla, resultó efectiva y permitió mantener la integridad de las señales de datos y alimentación sin interferir en la precisión del escaneo.

El segundo inconveniente surgió durante las pruebas finales, cuando la Raspberry Pi principal presentó fallas intermitentes de arranque (boot), lo que afectaba la estabilidad general del sistema.
Ante la falta de tiempo y recursos para una reparación completa, se decidió sustituirla temporalmente por una Raspberry Pi Pico, dispositivo de menor capacidad de procesamiento pero mayor confiabilidad operativa.
Esta modificación implicó delegar parte del procesamiento a una computadora externa, la cual asumió las tareas más demandantes del sistema, como la gestión del escaneo y la reconstrucción 3D.

Si bien esta solución redujo la autonomía del equipo, permitió completar las pruebas funcionales y validar el diseño general del sistema electrónico, priorizando la estabilidad y continuidad del proyecto frente a las restricciones de tiempo y presupuesto.

## 2.e. Conclusiones

### 2.e.i. Resultados técnicos alcanzados

El desarrollo del sistema UPFEET permitió integrar con éxito los principios de mecánica de precisión, electrónica aplicada y digitalización tridimensional, logrando un dispositivo funcional capaz de capturar y procesar la morfología plantar de manera precisa, portable y económica.

Desde el punto de vista estructural, se alcanzó una rigidez y estabilidad óptima, gracias al empleo de acero en la estructura principal y de apoyo, lo que asegura la correcta alineación del sistema óptico y la durabilidad del conjunto.

En el plano electrónico, la incorporación de drivers TMC2208 y motores NEMA 17 proporcionó un movimiento suave, silencioso y de alta resolución, adecuado para la calidad de escaneo requerida. La alimentación separada entre la sección de potencia (12 V) y la lógica de control (5 V) demostró ser una solución efectiva para evitar interferencias y garantizar la estabilidad del sistema.

Finalmente, el sistema alcanzó una coherencia integral entre diseño estructural, electrónica y software, consolidando una plataforma base lista para futuras mejoras de precisión y automatización.

### 2.e.ii. Ideas a implementar en un futuro

El proyecto UPFEET presenta un gran potencial de mejora, tanto en su precisión técnica como en la experiencia del usuario. Se proponen las siguientes líneas de evolución para futuras versiones:

1. Implementación de un código acústico de diagnóstico (beep):
Incorporar un pequeño buzzer o altavoz controlado por la Raspberry Pi para emitir códigos sonoros diferenciados que indiquen errores de conexión, sobrecorriente o falta de calibración.
Esto simplificará el proceso de diagnóstico y permitiría detectar fallas sin necesidad de interfaz visual, ideal para mantenimiento en campo.
2. Módulo adicional de escaneo corporal (postura y rodillas):
Integrar un segundo sistema de sensores que analice la alineación postural y el ángulo de las rodillas, mejorando la personalización del modelo 3D de las plantillas. Este complemento permitiría correlacionar la forma plantar con la distribución biomecánica del peso, aumentando la precisión de las recomendaciones

ortopédicas.

3. Optimización de la alimentación de los drivers:
Sustituir el actual banco de pilas por una batería recargable de litio con circuito de protección y regulación de 12 V, o bien una fuente conmutada DC-DC de salida estabilizada.
Esta mejora reduciría el mantenimiento, estabilizaría la tensión de los motores y extendería la autonomía del equipo.
4. Integración de control automatizado de corriente (Smart Vref):
Incorporar una regulación dinámica de corriente según la carga de los motores, mejorando la eficiencia energética y reduciendo el calentamiento del sistema.
5. Interfaz de usuario mejorada:
Desarrollar un panel de control gráfico o aplicación complementaria que permita visualizar en tiempo real los valores de escaneo, estado del sistema y errores detectados por el código acústico.

# 3. Impresora

## 3.a. Estructura mecanica

### 3.a.i. Estructura metálica

La estructura de la impresora 3D MakerPi P3 Pro se compone de un bastidor rígido de perfiles de aluminio extruido tipo V-Slot, en secciones 2020 y 2040. La configuración es ortogonal, formando un marco autoportante que sostiene los subsistemas de movimiento y extrusión.
Las uniones entre perfiles se efectúan mediante escuadras mecanizadas de aluminio y tornillería M5 con tuercas T-slot, asegurando acoplamientos rígidos y distribuyendo uniformemente los esfuerzos mecánicos.
La base principal constituye un marco rectangular que soporta los perfiles verticales, los cuales se fijan mediante escuadras internas y tornillería pasante, garantizando paralelismo y estabilidad torsional.
Los perfiles superiores cierran la estructura en pórtico, reduciendo la deflexión en los planos XY y Z bajo cargas dinámicas durante el funcionamiento. Todos los elementos metálicos se encuentran anodizados, incrementando la resistencia a la abrasión y a la corrosión.

### 3.a.ii. Justificación de las dimensiones y disposición estructural

Las dimensiones finales de la impresora modificada son 560 mm (ancho) × 540 mm (profundidad) × 400 mm (altura total), ajustadas para la producción de plantillas tridimensionales y la estabilidad estructural del bastidor.
⦁Los 560 mm de ancho permiten ubicar los perfiles horizontales del pórtico y soportar de manera estable el desplazamiento del extrusor en el eje X, reduciendo deflexión y garantizando la perpendicularidad con el eje Z.
⦁La profundidad de 540 mm asegura soporte robusto para el eje Y y la cama caliente, minimizando torsiones bajo las cargas dinámicas del movimiento de la plataforma y la deposición de filamento.
⦁La altura total de 400 mm fue reducida respecto al diseño original debido a que la aplicación principal —impresión de plantillas— no requiere un recorrido vertical amplio. Esta modificación elimina espacio innecesario sobre el área de impresión, disminuye el momento de inercia de la estructura y mantiene la rigidez torsional necesaria para movimientos dinámicos. La sección vertical de los perfiles 2040 sigue siendo suficiente para soportar el recorrido del eje Z y la instalación del portabobinas sobre el bastidor sin comprometer la funcionalidad ni la estabilidad de la impresora.
La disposición ortogonal cerrada de los perfiles y la selección de estas dimensiones optimizan la rigidez torsional, la alineación de ejes y la precisión dimensional, asegurando la correcta deposición de filamento flexible (TPU) dentro de las tolerancias requeridas para plantillas ortopédicas.
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

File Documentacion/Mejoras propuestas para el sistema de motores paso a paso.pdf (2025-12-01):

Mejoras propuestas para el sistema de motores paso a paso del proyecto UPFEET

A continuación se detallan las mejoras solicitadas para optimizar el rendimiento del sistema mecánico del escáner UPFEET. Estas mejoras apuntan a aumentar la velocidad de desplazamiento, reducir la latencia del programa y lograr un funcionamiento más eficiente de los motores NEMA 17.

______________________________________________________________________________

1. Implementación de control por PWM para los motores paso a paso

Objetivo: mejorar eficiencia y control de velocidad del motor.
Descripción:

Los motores paso a paso habitualmente se controlan mediante señales digitales de paso (STEP) y dirección (DIR). Sin embargo, se puede integrar PWM para modular la corriente entregada al motor a través del driver.

Esto permite:

- Un movimiento más fluido.
- Mejor control de aceleración y desaceleración.
- Mayor eficiencia energética.
- La Raspberry Pi Pico posee temporizadores y canales PWM suficientes para generar señales precisas sin saturar el CPU.
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

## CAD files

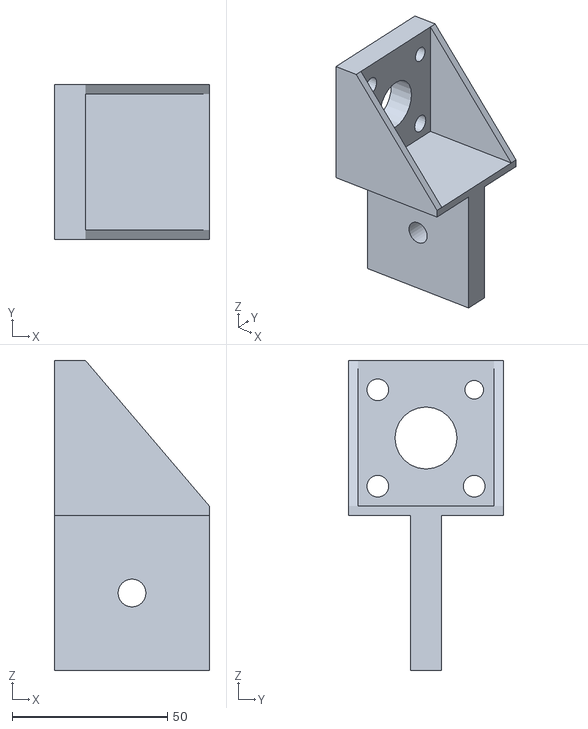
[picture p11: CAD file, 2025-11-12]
Soportes_3D/soporte_varilla_eje_x_1.stl
50.0 x 50.0 x 100.0

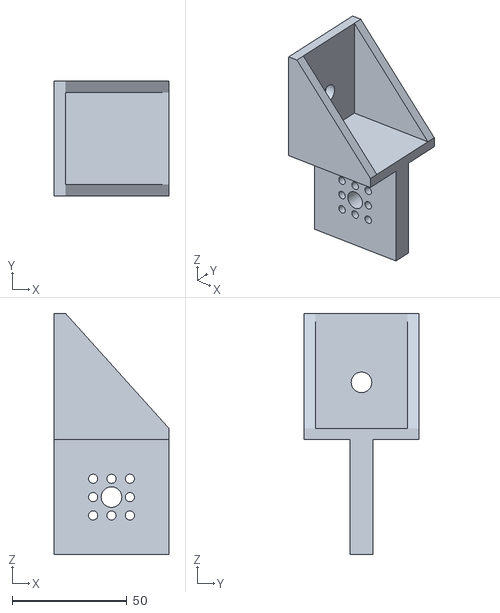
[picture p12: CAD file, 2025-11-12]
Soportes_3D/Soporte_del_otro_eje.stl
50.0 x 50.0 x 105.0

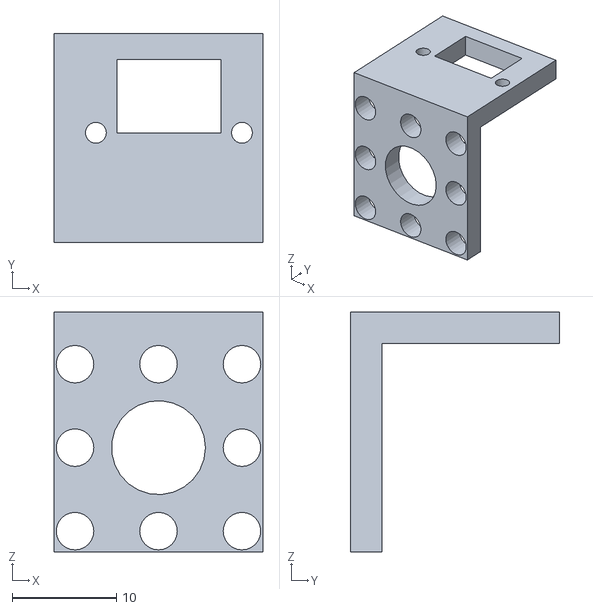
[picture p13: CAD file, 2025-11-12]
Soportes_3D/soprote_sensor.stl
20.0 x 20.0 x 23.0

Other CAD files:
Soportes_3D/chasis escaner.dwg
Soportes_3D/soporte.dwg

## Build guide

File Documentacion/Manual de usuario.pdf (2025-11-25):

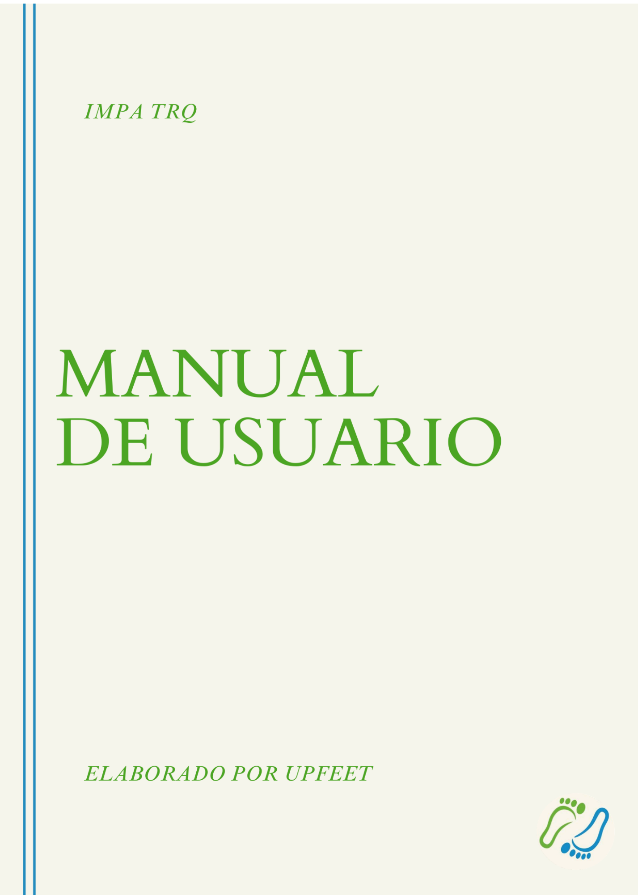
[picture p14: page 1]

# Indice

1. Introduccion
a. Objetivo
b. Características principales
i. Escaner
ii. Impresora
2. Escaner
a. Descripcion General
i. Partes Principales
ii. Identificación de Partes
b. Instalacion y conexion
i. Instalacion
ii. Ensamblaje y desamblaje
c. Mantenimiento
i. Limpieza General
ii. | Mantenimiento Electrónico
iii. | Mantenimiento Mecánico
iv. | Sensor Lidar
v. Recomendaciones generales
d. Uso
i. Preparacion
ii. | Procedimiento
iii. | Recomendaciones de uso
e. Soluciones a problemas comunes
i. Codigo beep
ii. | Fallas comunes
iii. | Recomendaciones ante fallos persistentes
f. Seguridad
i. Seguridad general
ii. | Seguridad electrica
iii. | Seguridad mecanica
iv. | Seguridad del usuario
v. Recomendaciones institucionales
3. Impresora
a. Descripción general
i. Componentes principales
ii. | Identificación de partes
iii. | Especificaciones técnicas
b. Instalación y conexión
i. Montaje inicial
ii. | Conexión eléctrica y de datos
iii. | Actualización o instalación de firmware
iv. | Configuración de la placa SKR 1.4
c. Preparación para imprimir
i. Nivelación de la cama
ii. Carga y descarga de filamento

iii. | Configuración de extrusores (sistema IDEX)
iv. | Calibración de ejes y extrusores
d. Uso del software
i. Slicers compatibles
ii. Configuración de perfiles de impresión
e. Proceso de impresión
i. Iniciar una impresión
ii. | Monitoreo del proceso
iii. | Finalización y retirada de la pieza
f. Mantenimiento
i. Limpieza general
ii. | Cambio de boquilla y lubricación de ejes
iii. | Revisión de correas, rodamientos y ventiladores
iv. | Calibración de la impresora
g. Solución de problemas
i. Fallos de impresión comunes
ii. | Atascos de filamento
iii. | Problemas de nivelación
iv. | Mensajes de error de la SKR 1.4
h. Seguridad
i. Precauciones generales
ii. | Recomendaciones durante la impresión
iii. | Manipulación de materiales
4. Anexos
a. Glosario de términos
b. Recursos y enlaces útiles
c. Contacto y soporte técnico

# 1.Introduccion

## 1.a. Objetivo

El presente manual tiene como objetivo brindar a los usuarios una guía clara, completa y accesible para la correcta utilización del sistema UpFeet 3D, destinado al escaneo, diseño y fabricación de plantillas ortopédicas personalizadas mediante tecnología de impresión 3D.

A través de este documento, se busca que el usuario pueda:

- Comprender el funcionamiento general del sistema y sus componentes.
- Conocer los procedimientos de escaneo, procesamiento y generación de modelos.
- Aplicar las medidas de seguridad y mantenimiento necesarias para garantizar un uso eficiente y prolongar la vida útil del equipo.

- Interpretar las interfaces del software y los pasos requeridos para la exportación e impresión de los archivos STL generados.

Este manual está dirigido a operadores técnicos, profesionales de la salud, docentes y estudiantes vinculados al área de la tecnología biomédica, así como a todo usuario que requiera fabricar plantillas personalizadas de forma precisa y segura.

El cumplimiento de las indicaciones contenidas en este manual permitirá optimizar la calidad de los resultados, minimizar errores en la calibración y asegurar una experiencia de uso confiable e intuitiva.

## 1.b. Características principales

### 1.b.i. Escaner

El escáner UpFeet 3D fue construido especialmente por Cronos Metalurgia, mediante un acuerdo de patrocinio y colaboración tecnológica. Su estructura metálica garantiza estabilidad, precisión y durabilidad en entornos de uso educativo y profesional.

Entre sus principales características se destacan:

- Estructura metálica cerrada, fabricada en acero.
- Dimensiones aproximadas: 250 × 400 × 300 mm.
- Ventana superior de escaneo, donde el usuario apoya el pie sobre una superficie de acrílico de policarbonato
- Sistema de movimiento tipo H-bot, que permite el desplazamiento controlado del módulo de captura.
- Tres motores paso a paso NEMA 17, montados sobre guías lineales de precisión.
- Placa controladora personalizada, con drivers integrados para los motores.
- Raspberry Pi 4, encargada del control de movimiento y procesamiento de datos.
- Conectividad: USB.
- Alimentación: 12 V CC.
- Diseño modular y de fácil mantenimiento.

### 1.b.ii. Impresora

Esta versión personalizada de la MakerPi P3 Pro se basa en el diseño original de la impresora IDEX, pero fue adaptada para funcionar con un solo extrusor, optimizando su desempeño y simplificando la operación.
Entre sus principales características se destacan:
- Sistema de impresión FDM (Modelado por Deposición Fundida).
- Un extrusor con boquilla estándar de 0,4 mm.
- Placa madre BTT SKR V1.4, con firmware Marlín configurado.
- Volumen de impresión aproximado: 300 × 300 × 260 mm.
- Estructura metálica con guías lineales de precisión.
- Conectividad mediante USB y tarjeta SD.
- Diseñada para imprimir plantillas 3D obtenidas por escaneo, garantizando precisión dimensional y buena calidad superficial.

# 2. Escaner

## 2.a. Descripción General

### 2.a.i Partes principales

Estructura metálica principal:
Caja rígida fabricada por Cronos Metalurgia, que brinda soporte y protección a todos los componentes internos.

Ventana de escaneo:
Superficie transparente superior (acrílico de policarbonato) sobre la que el usuario apoya el pie. Permite la toma de imágenes o datos sin interferencias.

Sistema de movimiento tipo H-bot:
Conjunto de varillas sincronizadas que posibilitan el desplazamiento del módulo de captura a lo largo de los ejes X e Y.

Motores paso a paso NEMA 17:
Tres unidades que accionan el sistema de movimiento, garantizando precisión y suavidad en el desplazamiento.

Módulo de captura:
Conformado por la cámara y/o sensores encargados de registrar la morfología del pie y transmitir los datos a la unidad de control.

Placa controladora:
Circuito que integra los drivers de los motores y coordina las señales provenientes de la

Raspberry Pi 4.

Raspberry Pi 4:
Microcomputadora central del sistema. Controla el movimiento, procesa la información obtenida y envía los datos al software generador del modelo 3D.

Fuente de alimentación:
Suministra energía estable (12 V CC) al sistema.
Puertos de comunicación:
Conectores USB, que permiten la interfaz con periféricos

### 2.a.ii. Identificación de Partes

## 2.b. Instalación y conexiones

### 2.b.i. Instalacion

Su instalación no requiere conocimientos avanzados, aunque debe realizarse con cuidado para garantizar un funcionamiento correcto y evitar daños en los componentes.

Procedimiento básico:

1. Ubicación:
Colocar el escáner sobre una superficie firme y nivelada, en un entorno seco y bien ventilado.
Se recomienda mantenerlo próximo a la impresora 3D para evitar tensiones o tirones en el cable USB.
2. Conexión eléctrica:
- Conectar el cable de alimentación principal del escáner a un tomacorriente estándar.
3. Conexión de datos:
- Enchufar el cable USB del escáner al puerto correspondiente de la impresora 3D.
- Verificar que el cable no quede tirante ni en zonas de tránsito o riesgo de desconexión.
4. Verificación inicial:
Una vez conectadas las fuentes de alimentación, comprobar que los indicadores luminosos del sistema (Raspberry Pi y controladora) se encienden correctamente. El sistema estará listo para ser reconocido por el software de control de UpFeet 3D.

### 2.b.ii. Ensamblaje y desamblaje

El escáner UpFeet 3D fue diseñado con un sistema de cierre atornillado que permite su mantenimiento y revisión interna cuando sea necesario.
Para estas tareas se requiere el uso de herramientas manuales básicas.

Herramientas necesarias:

- Llave Allen de 4 mm: para remover los tornillos externos con cabeza hexagonal.
- Destornillador Phillips de 5 mm o menor: para aflojar tornillos con cabeza en cruz en la carcasa o borneras.
- Precaución: al manipular los tornillos, mantener el equipo desconectado de la red eléctrica.

Componentes internos alimentados:

- Los drivers del sistema se alimentan mediante pilas AA internas, que suministran una tensión de 12 V a los motores.
- La Raspberry Pi 4 utiliza su cargador externo propio de 5 V, independiente de la alimentación de los motores.

Procedimiento general de apertura:

1. Desconectar completamente el escáner de la corriente.
2. Retirar los tornillos externos según corresponda al tipo de cabeza.
3. Levantar con cuidado la tapa superior para acceder al interior.
4. Realizar el mantenimiento necesario o la sustitución de componentes.
5. Volver a cerrar asegurando todos los tornillos, sin exceder la fuerza de apriete.

## 2.c. Mantenimiento

El mantenimiento del escáner UpFeet 3D debe realizarse de manera preventiva para asegurar un funcionamiento estable, prolongar la vida útil de los componentes mecánicos y electrónicos, y conservar la precisión de escaneo.
Se recomienda efectuar las tareas de revisión cada 3 meses o luego de 50 horas de uso continuo.

### 2.c.i. Limpieza General

- Desconectar completamente el equipo de la red eléctrica antes de comenzar.
- Limpiar la superficie de vidrio o acrílico con un paño suave y alcohol isopropílico; evitar solventes abrasivos.
- Retirar polvo y residuos del interior mediante aire comprimido o pincel seco, especialmente en zonas de ventilación y ejes.
- Evitar el contacto de líquidos con los componentes electrónicos.

### 2.c.ii. Mantenimiento Electrónico

Raspberry Pi 4

- Mantener las ranuras de ventilación libres de polvo.
- Verificar el correcto asiento del cable de alimentación y de los conectores USB.
- No cubrir la carcasa durante el funcionamiento para evitar sobrecalentamiento.

Alimentación y baterías internas

- Reemplazar las pilas AA de los drivers cada 6 meses o ante signos de pérdida de potencia (movimientos erráticos o ruidos en los motores).
- Comprobar que los contactos metálicos estén limpios y sin corrosión.

Cableado y conectores

- Revisar periódicamente los conectores USB, HDMI y de alimentación.
- Asegurar que los cables no estén tirantes ni doblados en ángulos cerrados.

### 2.c.iii. Mantenimiento Mecánico

Varillas roscadas y rieles lineales

- Aplicar una fina capa de grasa de litio o aceite liviano cada dos meses para reducir la fricción.
- Verificar que las varillas no presenten dobleces ni desgaste irregular.

Acoples flexibles (5 mm – 8 mm)

- Revisar que los tornillos prisioneros estén firmes, sin holgura entre motor y varilla.
- Sustituir el acople si se observa deformación o fisura.

Tuercas anti-backlash

- Comprobar que mantengan presión uniforme sobre la varilla.
- Ajustar ligeramente el resorte si se detecta juego o pérdida de precisión.

Plataformas 3D y uniones de ejes

- Asegurar que no haya fisuras en las piezas impresas.
- En caso de desgaste, reimprimir el componente en PLA + o PETG para mantener rigidez estructural.

### 2.c. iv. Sensor lidar

- Limpiar la lente del sensor con un paño de microfibra seco.
- Evitar la exposición directa al sol o a fuentes de calor.
- Comprobar periódicamente la alineación del sensor respecto al plano de escaneo; cualquier desplazamiento puede afectar la precisión de lectura.
- Si se detectan lecturas erráticas, revisar la conexión de datos a la Raspberry Pi y recalibrar el módulo según el procedimiento de software.

### 2.c.v. Recomendaciones generales

- No realizar modificaciones eléctricas sin autorización técnica.
- Guardar el escáner en un lugar seco, sin humedad ni polvo.
- Documentar cada mantenimiento en una planilla de control con fecha, tareas realizadas y observaciones.

## 2.d. Uso

### 2.d.i. Preparacion

Antes de iniciar el escaneo:

1. Asegurarse de que el escáner esté correctamente conectado a la red eléctrica y a la impresora 3D mediante el cable USB.
2. Verificar que el equipo se encuentre sobre una superficie estable y nivelada.
3. Ubicar la plataforma de apoyo auxiliar (provista junto al sistema) al lado del escáner.
4. Encender el sistema y esperar a que las luces indicadoras de la Raspberry Pi 4 confirmen el inicio correcto.

### 2.d.ii. Procedimiento

Colocación inicial:
El usuario debe pararse primero sobre la plataforma de apoyo ubicada al costado del escáner.
Esto permite acomodarse con estabilidad y evita aplicar peso directamente sobre el vidrio del escáner antes de tiempo.

Posicionamiento del pie:
Una vez estabilizado, apoyar con cuidado el pie a escanear sobre la ventana superior del escáner.
El vidrio está diseñado para soportar el peso del pie, pero no saltos ni movimientos bruscos.

Inicio del escaneo:
Presionar el botón de inicio ubicado en el panel frontal.
El sistema comenzará el recorrido automático del cabezal con el sensor TF-LC02.
Durante este proceso, se recomienda permanecer inmóvil para obtener una lectura precisa.

Finalización:
El escaneo finaliza automáticamente cuando se escucha un pequeño sonido mecánico, indicando que el movimiento de los ejes se detuvo.
En ese momento, retirar el pie con cuidado y esperar la confirmación del software antes de iniciar un nuevo escaneo.

### 2.d.iii. Recomendaciones de uso

- No ejercer fuerza excesiva sobre la ventana del escáner.
- No interrumpir el proceso de escaneo ni desconectar los cables mientras el sistema está en funcionamiento.
- Evitar movimientos o cambios de postura durante la captura.
- Utilizar el escáner en un ambiente sin vibraciones ni luz solar directa.

## 2.e. Soluciones a problemas comunes

### 2.e.i. Codigo beep (a implementar)

El sistema UpFeet 3D cuenta con un pequeño buzzer que emite señales sonoras (“beeps”) ante distintas condiciones de error o advertencia.
Estas alertas ayudan a identificar rápidamente el origen del problema sin necesidad de conectar el sistema a un monitor o software de diagnóstico.
Código sonoro | Descripción del problema | Posible causa | Solución recomendada
1 beep corto | Escáner listo para operar | Secuencia de inicio normal | No requiere acción
2 beeps cortos | Fallo de conexión USB | Cable suelto o mal conectado a la impresora / Raspberry Pi | Revisar conexión USB y reiniciar el sistema
3 beeps cortos | Falla de motor o atasco mecánico | Varilla o correas trabadas, acople flojo, tuerca anti-backlash desajustada | Apagar el equipo, liberar el movimiento y lubricar las guías
4 beeps cortos | Error del sensor TF-LC02 | Sensor desconectado o sin lectura | Verificar el conector del sensor y su alineación
5 beeps cortos | Fallo de alimentación de drivers | Pilas AA agotadas o con mal contacto | Reemplazar las pilas y limpiar los contactos metálicos
1 beep largo + 2 cortos | Error de sistema en Raspberry Pi | Software no inicia o SD dañada | Revisar tarjeta microSD, reinstalar sistema operativo

### 2.e.ii. Fallas comunes sin código sonoro

Síntoma | Causa probable | Solución
El escáner no enciende | Cable de alimentación desconectado o fuente defectuosa | Revisar tomacorriente y fusible interno
No se detecta en la Raspberry Pi | Problemas con el puerto USB o falta de drivers | Reiniciar la Pi y reconectar el dispositivo
El motor hace ruido pero no se mueve | Acople flojo o varilla trabada | Ajustar tornillos del acople flexible y lubricar
El sensor no registra datos | Suciedad en la lente o sensor mal alineado | Limpiar la lente y verificar posición
El escaneo se interrumpe antes de finalizar | Pilas agotadas o caída de tensión | Reemplazar baterías y revisar conexiones
Imagen distorsionada o incompleta | Vibraciones o movimiento del pie durante el escaneo | Repetir el proceso manteniendo el pie inmóvil
Luces de la Raspberry Pi no encienden | Falta de alimentación o cargador defectuoso | Revisar adaptador de 5 V y cable micro-USB

### 2.e.iii. Recomendaciones ante fallos persistentes

- Reiniciar completamente el sistema y repetir el proceso desde el inicio.
- No intentar forzar el movimiento manual de los ejes con el equipo encendido.
| | | o imagen del software UpFeet
1 beep largo + 3 cortos | Temperatura elevada en Raspberry Pi | Ventilación obstruida o exceso de calor | Apagar, limpiar ventilación y esperar enfriamiento
Serie continua de beeps | Error crítico | Desconexión de componentes internos o falla de control | Apagar inmediatamente y verificar cableado interno

- Si el error persiste, anotar el código de beep, apagar el escáner y consultar el soporte técnico o docente responsable.
- Mantener registro de las incidencias en la planilla de mantenimiento del equipo.

## 2.f. Seguridad

### 2.f.i. Seguridad general

- Operar el escáner únicamente bajo la supervisión de personal capacitado o docente responsable.
- No retirar tapas ni paneles mientras el equipo esté conectado a la red eléctrica.
- Mantener el área de trabajo limpia, seca y libre de objetos que puedan interferir con el movimiento del sistema.
- No colocar herramientas metálicas o líquidos sobre el escáner.
- No utilizar el equipo si se detectan cables dañados, chispas, olor a quemado o ruidos inusuales.

### 2.f.ii. Seguridad electrica

- Utilizar únicamente tomas de 220 V con conexión a tierra.
- No conectar ni desconectar cables con el equipo encendido.
- Verificar periódicamente el estado de los cables de alimentación y conectores USB.
- No manipular la Raspberry Pi, los drivers o las pilas internas mientras haya corriente conectada.
- Reemplazar las pilas AA solo con el equipo apagado y desconectado de la red.

### 2.f.iii. Seguridad Mecanica

- No introducir manos, herramientas o materiales dentro del escáner mientras los ejes estén en movimiento.
- Evitar apoyarse o ejercer fuerza sobre la superficie de vidrio.
- En caso de trabarse el sistema de ejes, apagar inmediatamente el equipo antes de intentar liberar el movimiento.

- Manipular las piezas internas (varillas, acoples, tuercas) solo con herramientas adecuadas y sin aplicar fuerza excesiva.

### 2.f.iv. Seguridad del usuario

- No utilizar el escáner con los pies mojados o sucios.
- Apoyar el pie únicamente cuando el sistema lo indique, utilizando previamente la plataforma de apoyo auxiliar.
- Mantener la postura estable durante el escaneo para evitar caídas o roturas del vidrio.
- No dejar el equipo encendido sin supervisión.

### 2.f.v. Recomendaciones institucionales

- Cumplir con las normas de higiene y seguridad establecidas por la Ley 19.587 y el Decreto 351/79, vigentes en el ámbito educativo-técnico.
- El equipo debe contar con un corte de energía accesible (enchufe o interruptor) y cartelería visible que indique “Equipo en funcionamiento”.
- Ante cualquier inconveniente eléctrico o mecánico, notificar al docente o encargado de mantenimiento antes de continuar su uso.

# 3. Impresora

## 3.a. Descripcion General

### 3.a.i Componentes principales

La impresora 3D MakerPi P3 Pro (versión modificada) está compuesta por una estructura metálica robusta y componentes mecánicos y electrónicos de alta precisión. A continuación, se detallan las principales partes del equipo:
- Estructura principal: bastidor metálico que sostiene todos los componentes.
- Cama caliente: superficie de impresión calefaccionada, utilizada para mejorar la adhesión de las piezas.
- Cabezal de impresión (Hotend): calienta y funde el filamento para depositarlo capa por capa.
- Extrusor: mecanismo que empuja el filamento hacia el hotend.

- Eje X, Y y Z: permiten el movimiento preciso del cabezal y la cama.
- Motor paso a paso (NEMA 17): accionan los ejes y el extrusor.
- Placa madre BTT SKR 1.4: controla el funcionamiento general de la impresora (movimientos, temperatura, comunicación, etc.).
- Fuente de alimentación: suministra la energía necesaria para todos los componentes.
- Ventiladores de enfriamiento: mantienen la temperatura adecuada en el hotend y en la placa.
- Sensor de final de carrera: determina los límites de movimiento en cada eje.
- Portabobinas: sostiene la bobina de filamento.
- Cable USB y tarjeta SD: medios de comunicación y transferencia de archivos de impresión.

### 3.a.ii: AGREGAR FOTO DE LA IMPRESORA CON NUMEROS INDICANDO CADA PARTE

### 3.a.iii: Especificaciones técnicas

Parámetro | Valor/descripción
Tecnología de impresión | FDM (modelado por deposición fundida)
Volumen de impresión | 300x300x260
Numero de extrusores | 1
Diámetro de boquilla | 0.4 mm (intercambiable)
Materiales compatibles | PLA, ABS, PETG, TPU
Diámetro de filamento | 1,75 mm
Temperatura máxima de hotend | 260°
Temperatura máxima de cama caliente | 100°
Firmware | Marlín (basado en BIQU V1)
Tensión de alimentación | 12V o 24V (según fuente instalada)
Peso estimado | 20-25kg aprox

## 3.b. Instalacion y conexion

### 3.b.i: Montaje inicial

La impresora 3D MakerPi P3 Pro (versión modificada) puede venir semi-ensamblada o completamente armada, dependiendo de la configuración.
Antes de encenderla, asegúrate de revisar lo siguiente:
- Coloca la impresora sobre una superficie firme, nivelada y estable.2.
- Verifica que todos los pernos y tornillos estén bien ajustados.
- Asegúrate de que los cables de los motores, sensores y ventiladores estén correctamente conectados a la placa SKR 1.4 (según el esquema del firmware).

- Conecta el Portabobinas en la parte superior o lateral, según el diseño.
- Revisa que el carro del eje X y la cama del eje Y se muevan libremente, sin trabas.
- Confirma que los finales de carrera estén firmemente sujetos y funcionando.
- Consejo: no fuerces los ejes a mano si notas resistencia; comprobá que las correas estén bien tensadas, pero sin exceso

### 3.b.ii: Conexión eléctrica y de datos

1. Asegúrate de que el interruptor general esté en la posición apagado (OFF).
2. Conectá el cable de alimentación a la fuente de la impresora y enchúfalo a una toma con conexión a tierra.
3. Verificá que la fuente esté configurada a la tensión correcta (220 V para Argentina) antes de encenderla.
4. Encendé la impresora y comprobá que la pantalla LCD encienda correctamente.
5. Para la conexión al software:
- Por USB: La conexión USB permite controlar la impresora directamente desde el software de laminado o desde un programa host (como Pronterface o OctoPrint).
- Por tarjeta SD: La conexión por tarjeta SD permite imprimir de forma autónoma, sin depender de la computadora. Los archivos generados por el software de laminado se guardan en la tarjeta y se ejecutan directamente desde la impresora a través del menú “Print from SD”.

### 3.b.iii: Instalación o actualización de firmware

- Descargar el archivo de firmware modificado desde la fuente oficial del proyecto (firmware.bin)
- Verificar que el archivo este correctamente nombrado como firmware.bin antes de copiarlo
- Copiar el archivo en el directorio principal de la tarjeta microSD
- Con la impresora apagada, insertar la tarjeta microSD en la ranura de la placa SKR V1.4
- Encender la impresora y esperar unos segundos
- La placa cargara automáticamente el nuevo firmware y renombrara el archivo
- Reiniciar la impresora y verificar que la pantalla inicial y los controles respondan correctamente
- Verificar que los sensores de temperatura, los finales de carrera y los motores funcionen de forma correcta

### 3.b.iv: Configuración inicial de la placa SKR 1.4

La placa BigTreeTech SKR V1.4 actúa como el cerebro de la impresora, controlando los movimientos de los motores, la temperatura del hotend y la cama, además de la comunicación con el software de impresión.

Para su correcto funcionamiento, fue configurada con un firmware basado en la BIQU V1, modificado específicamente para operar con un solo extrusor y los componentes instalados en esta impresora.
- Instalacion de drivers y componentes: utiliza drivers TMC 2208, Se deben conectar los motores en los ejes X, Y, Z y el del extrusor respetando la polaridad y la orientación de los conectores y por ultimo verificar la conexión de los finales de carrera y los sensores de temperatura
- Ajustes del firmware: configurar los pasos por milímetro de cada eje en el archivo “configuration.h”, ajustar la dirección de giro de los motores para asegurar un movimiento correcto, y por último establecer los límites de temperatura seguros para el hotend
- Calibracion inicial: Ejecutar el comando Autohome para comprobar el correcto funcionamiento de los finales de carrera, verificar que el cabezal regresara al punto de origen sin colisiones y realizar una nivelación manual de la cama antes de la primera impresión

## 3.c. Preparación para imprimir

### 3.c.i: Nivelación de la cama

- Una cama bien nivelada garantiza que la primera capa se adhiera correctamente y la pieza salga con buena calidad.
- Procedimiento:
- Encendé la impresora y espera a que inicie correctamente
- Desde el menú, selecciona la opción “Home All” para llevar los ejes X, Y y Z a su posición inicial.
- Coloca una hoja de papel entre la boquilla y la cama caliente.
- Ajustá los tornillos de nivelación hasta que sientas una leve fricción al mover el papel.
- Repetí este proceso en las cuatro esquinas y en el centro.
- Guarda la configuración si el firmware lo permite

### 3.c.ii: Carga de filamento

Antes de imprimir, se debe cargar el filamento correctamente en el extrusor
Pasos:
1. Precalentá el hotend desde el menú
2. Espera a que alcance la temperatura de trabajo (por ejemplo, 200 °C para PLA).
3. Coloca la bobina de filamento en el Portabobinas.
4. Introducí el extremo del filamento en el tubo PTFE y empújalo hasta que entre al extrusor(debe existir una forma para extruir manualmente, tengo que preguntar eso)

5. Limpia el exceso de filamento antes de comenzar a imprimir
6. Consejo: corta el extremo del filamento en punta para facilitar su entrada

### 3.c.iii: Calibración de ejes y extrusor

Una calibración correcta evita errores dimensionales y asegura que el material se deposite con precisión
Verificación básica:
- Mové los ejes X, Y y Z desde el menú y asegúrate de que se desplacen sin trabas ni ruidos extraños.
- Comprobá que el movimiento de 10 mm en pantalla sea realmente de 10 mm en la impresora (podes medirlo con una regla o calibre).
- Revisa que el extrusor extruya el material correctamente sin saltos o ruidos.
- Si notas diferencias, Ajustá los steps/mm de cada eje en el firmware o desde el menú

### 3.c.iv: Preparación del archivo de impresión

Antes de enviar un modelo a la impresora, es necesario procesarlo en un software de laminado (slicer) para generar el archivo. gcode, que contiene todas las instrucciones que seguirá la impresora durante la impresión.
- Importar el modelo 3D: Abrir el archivo del objeto (formato .STL) en el slicer
- Seleccionar el material de impresión: Elegir TPU como filamento y cargar el perfil personalizado correspondiente a la impresora
- Configurar parámetros de impresión: Altura de capa, relleno, soporte y adherencia a la cama según las características de la pieza y ajustes específicos para TPU (como velocidad reducida y retracción mínima)
- Generar el archivo G-code: una vez ajustados todos los parámetros, exportar el archivo en formato .gcode y guardar el archivo en la computadora o en una tarjeta microSD para enviarlo a la impresora

### 3.c.v: Prueba inicial

Antes de una impresión real:
- Imprimí una pieza de prueba (como un cubo de calibración)
- Revisa la adhesión de la primera capa
- Ajusta la altura del eje Z si el filamento queda muy aplastado o no se pega bien
- Confirma que no haya vibraciones ni movimientos extraños durante la impresión

## 3.d. Uso del Software

### 3.d.i: Slicers compatibles

La impresora es compatible con los principales programas de laminado o “Slicers” del marcado, que permiten preparar los modelos 3D para su impresión. Por ejemplo:
- Ultimaker Cura
- PrusaSlicer
- Simplify3D
Estos programas generan archivos en formato .gcode, que contienen todas las instrucciones necesarias para la impresora, como movimientos, temperaturas y velocidades.

### 3.d.ii: Configuración de perfiles de impresión

Para obtener resultados óptimos, se recomienda crear un perfil personalizado de impresión que se ajuste a las características del equipo y del material utilizado
- Tamaño de la cama 300x300mm
- Altura de capa: entre 0,1 y 0,3mm según el detalle deseado
- Temperatura del hotend: 210-230° C para TPU
- Temperatura de la cama: 60° para TPU
- Velocidad de impresión: 20-30mm/s para TPU
- Diámetro de boquilla: 0.4mm
- Retracción: 2mm o menos, para evitar atascos

## 3.e. Preparación para imprimir

### 3.e.i: Iniciar una impresión

1. Encendido: conectar el cable de alimentación y encender el interruptor principal ubicado en la parte trasera de la impresora.
2. Preparación del filamento:
Calentar el extrusor desde el menú “Preparar → Calentar extrusor” (200–210 °C para PLA). Introducir el filamento por el tubo PTFE hasta el extrusor.
Extruir unos milímetros para confirmar que el material fluye correctamente.
3. Nivelación de la cama:
Asegurarse de que la cama esté limpia, firme y correctamente nivelada.
En caso de tener auto nivelado, ejecutar el comando “Auto home” o “Nivelar cama”.
4. Carga del archivo:
Insertar la tarjeta SD con el archivo GCODE generado desde el slicer.
En el menú LCD, seleccionar “Imprimir desde SD” y elegir el archivo deseado.
Inicio: confirmar la impresión y esperar que el nozzle y la cama alcancen la temperatura configurada.
Observar las primeras capas para comprobar una buena adhesión a la cama y el flujo correcto del material.

### 3.e.ii: Monitoreo del proceso

Durante la impresión es importante supervisar el funcionamiento general del equipo:
- Verificar que el filamento se alimente sin interrupciones
- Controlar la adherencia de las capas y que no haya desplazamientos o deformaciones
- Evitar mover o golpear la impresora mientras esté trabajando
- Si se detecta un problema (por ejemplo, el filamento se enreda o el nozzle se obstruye), pausa la impresión desde el menú antes de intervenir
- No tocar el cabezal ni la cama mientras estén calientes

### 3.e.iii: Finalización y retirada de la pieza

- Esperar que el proceso finalice completamente y el cabezal regrese a la posición original
- Dejar que la cama se enfrié antes de retirar la pieza, para evitar deformaciones
- Si es necesario, usar una espátula o herramienta plástica para desprender la pieza con cuidado
- Apagar la impresora desde el interruptor principal
- Retirar el filamento si no se va a utilizar nuevamente, calentando el extrusor y extrayéndolo con suavidad
- Limpiar la superficie de la cama y revisar que no queden restos del material Consejo: guardar los archivos GCODE utilizados en una carpeta aparte para futuras reimpresiones o ajustes

## 3.f. Mantenimiento

### 3.f.i: Limpieza general

- Limpiar regularmente la superficie de la cama con alcohol isopropílico y un paño suave para eliminar restos de filamento o adhesivo
- Retirar el polvo o residuos de los ejes, guías lineales y ventiladores con aire comprimido o un pincel fino
- Revisar el tubo PTFE y el extrusor para asegurarse de que no haya obstrucciones
- Mantener el entorno de trabajo libre de polvo y humedad
- Evitar el uso de solventes fuertes o productos abrasivos sobre las piezas plásticas

### 3.f.ii: Cambio de boquilla y lubricación de ejes

Cambio de boquilla:
- Calentar el extrusor a la temperatura de trabajo del material
- Con una herramienta adecuada, sostener el bloque calefactor y desenroscar la boquilla con cuidado
- Colocar la nueva boquilla y ajustar suavemente sin aplicar exceso de fuerza
- Verificar que no haya perdida de material en la unión durante la próxima impresión Lubricación de ejes:

- Aplicar una fina capa de grasa o aceite liviano sobre las guías lineales y varillas roscadas
- Desplazar manualmente los ejes X, Y y Z para distribuir uniformemente la lubricación
- No aplicar en exceso, ya que podría atraer polvos o residuos

### 3.f.iii: Revisión de correas, rodamientos y ventiladores

- Correas: comprobar la tensión de las correas de los ejes X e Y. deben estar firmes, pero no excesivamente tirantes. Ajustar con las tuercas tensoras si es necesario
- Rodamientos y carros: verificar que los movimientos sean suaves y sin ruidos extraños. Si hay fricción o trabas, limpiar y volver a lubricar las guías
- Ventiladores: revisar que los ventiladores del extrusor, fuente y placa madre funcionen correctamente y no estén bloqueados por polvo o filamento
Consejo: realizar una revisión general cada 50 horas de impresión o al menos una vez por mes si el uso es frecuente

### 3.f.iv. Calibración de la impresora

Nivelación de la Cama (Bed Leveling)
Frecuencia recomendada:
Una vez por semana, en uso regular.Cada 2–3 días si imprimís muchas horas por día. Inmediatamente después de: mover la impresora, cambiar superficie o detectar mala primera capa.
Procedimiento (Cura + impresora):
- En la impresora: Prepare → Leveling.
- Imprimir en Cura un “First Layer Test”.
- Ajustar Z o tornillos de cama hasta obtener una primera capa uniforme.

Ajuste del Z-Offset
Frecuencia recomendada:
Solo cuando cambiaste boquilla, cambiaste superficie (PEI, vidrio, etc.), O si ves la primera capa muy alta/baja. Normalmente: cada 1–2 meses como máximo.
Procedimiento:
- Menu impresora → Motion → Z-offset.
- Imprimir pieza pequeña desde Cura.
- Ajustar en pasos de 0.02 mm.

Calibración de Extrusión (E-Steps)
Frecuencia recomendada:
Tras cambiar extrusor o engranajes o si hay subextrusión o sobreextrusión persistente. Normalmente: 1 vez al año o cuando cambias hardware.
Procedimiento:
- Configurar Cura a baja velocidad (30 mm/s).
- Marcar 120 mm de filamento.
- Extruir 100 mm.
- Medir y corregir E-steps en: Control → Motion → E-steps.

Calibración de Flujo (Flow Rate) en Cura
Frecuencia recomendada:
Cada vez que cambias de marca o color de PLA, o si ves paredes muy gruesas o finas. Normal: cada 1–2 bobinas de filamento.
Procedimiento:
- En Cura: Flow = 100 %.
- Imprimir cubo de pared simple.
- Medir espesor.
- Ajustar Flow en 1–2 % según resultado.

Calibración de Temperatura para PLA (Tower Test)
Frecuencia recomendada:
Con cada bobina nueva de PLA. Si notas stringing o mala calidad de superficie. Normal: una vez por bobina.
Procedimiento:
- En Cura: Calibration Shapes → Temperature Tower.
- Imprimir entre 190–215 °C.
- Elegir la mejor zona.
- Usar esa temperatura en tu perfil.

Calibración de Retracción (Retraction)
Frecuencia recomendada:
Al cambiar de filamento o marca. Cuando aparece stringing. Normal: cada 1–2 meses, o cuando cambias PLA.
Procedimiento:
- Cura → activar Retraction.
- Imprimir Retraction Test.
- Ajustar distancia y velocidad hasta minimizar hilos.

## 3.g Solución de problemas

### 3.g.i: Fallos de impresión comunes

Problema | Posible causa | Solución
La primera capa no se adhiere a la cama | Cama sucia o mal nivelada | Limpiar la cama con alcohol isopropílico y volver a nivelar
Filamento no sale del nozzle | Boquilla obstruida o filamento mal insertado | Calentar el extrusor y purgar manualmente el filamento

a pieza se despega o se levanta en las esquinas | Temperatura de cama baja o mala adhesión | Aumentar la temperatura de cama a 60 °C o usar Brim/Raft.
Capas desalineadas | Correas flojas o movimiento trabado | Revisar la tensión de las correas y lubricar guías.
Filamento se corta o atasca | Rueda dentada sucia o presión del extrusor incorrecta | Limpiar la rueda y ajustar la presión del resorte.
Superficie rugosa o con hilos | Temperatura del nozzle demasiado alta o retracción incorrecta | Bajar temperatura 5–10 °C y revisar configuración de retracción.

### 3.g.ii: Atascos de filamento

Los atascos pueden ocurrir por acumulación de material dentro del hotend o por el uso de filamento húmedo o de baja calidad.
Procedimiento de desatasco:
1. Calentar el extrusor a la temperatura del material
2. Retirar el filamento actual desde el menú “Mover eje → Extrusor”.
3. Si no se puede extraer, subir la temperatura unos grados mas y tirar suavemente
4. Insertar un nuevo filamento y extruir hasta que fluya sin interrupciones
5. Si persiste el atasco, desmontar el hotend y limpiar manualmente la boquilla con una aguja o aguja de limpieza
Consejo: almacenar el filamento en un lugar seco o con bolsas desecantes para evitar humedad

### 3.g.iii: Problemas de nivelación

Una cama mal nivelada puede generar piezas deformadas o que no se adhieran correctamente
Problemas y soluciones rápidas:
El nozzle esta muy alto: el filamento no se adhiere → bajar ligeramente la cama o ajustar el tornillo correspondiente.
El nozzle está muy bajo: el filamento se aplasta o no sale → subir un poco la cama.
La primera capa desigual: realizar una nueva nivelación con la hoja de papel en las cuatro esquinas y el centro.

Recomendación: verificar el nivel antes de cada impresión importante

### 3.g.iv: Mensajes de error de la SKR V1.4

La placa madre SKR V1.4 puede mostrar mensajes de error en la pantalla o por conexión USB

Mensaje / Código | Causa posible | Solución
THERMAL RUNAWAY | Sensor de temperatura desconectado o daño en el termistor | Apagar la impresora, revisar la conexión del termistor y el cartucho calefactor.
MINTEMP / MAXTEMP | Lectura fuera del rango permitido | Revisar sensores, cables y conectores del hotend o de la cama.
Homing Failed | Algún endstop no se activa o está mal cableado | Comprobar la conexión en la placa (E0, X-, Y-, Z-) y su funcionamiento manual.
SD Init Fail | La tarjeta SD no es reconocida | Extraer y volver a insertar; si falla, reformatear en FAT32 o probar otra tarjeta.
EEPROM Error | Error en la memoria interna del firmware | Regrabar o reiniciar la EEPROM desde el menú de configuración de Marlín.

## 3.h. Seguridad

### 3.h.i: Precauciones generales

Antes de encender la impresora se debe comprobar que todos los componentes estén correctamente conectados y en buen estado. Es importante evitar el contacto con partes calientes o móviles mientras el equipo esté en funcionamiento. La impresora debe colocarse sobre una superficie firme, lejos de materiales inflamables y en un área ventilada.

### 3.h.ii: Recomendaciones durante la impresión:

Durante la impresión no se recomienda dejar la máquina sin supervisión por largos períodos. Es necesario controlar la temperatura del hotend y de la cama caliente para prevenir sobrecalentamientos. Tampoco se deben tocar las piezas recién terminadas hasta que se enfríen completamente, ya que pueden causar quemaduras. Si se detectan ruidos o movimientos anormales, se debe pausar el trabajo y revisar el equipo.

### 3.h.iii: Manipulación de materiales:

Los filamentos deben almacenarse en lugares secos y alejados de la humedad para conservar su calidad. Al usar materiales como ABS o Nylon, se recomienda mantener una buena ventilación o utilizar sistemas de extracción, ya que pueden liberar vapores. Además, se deben usar guantes al manipular alcohol isopropílico u otros productos de limpieza empleados en la preparación de la cama o el mantenimiento del extrusor.

# 4. Anexo

## 4.a: Glosario de términos:

Extrusor: Componente encargado de fundir y depositar el filamento capa por capa para formar la pieza
Hotend: Parte del extrusor donde el filamento se calienta hasta alcanzar su punto de fusión Cama caliente: Superficie donde se adhiere la pieza durante la impresión
G-code: Archivo que contiene las instrucciones que sigue la impresora para realizar la impresión
Slicer: Programa que convierte un modelo 3D en un archivo G-code, dividiendo el objeto por capa
Filamento: Material plástico utilizado para imprimir

## 4.b: Recursos y enlaces útiles:

## 4.c: Contacto y soporte técnico:

Para asistencia técnica o consultas sobre el funcionamiento de la impresora, comunicarse con el desarrollador del proyecto. https://vzaccari33.wixsite.com/upfeet

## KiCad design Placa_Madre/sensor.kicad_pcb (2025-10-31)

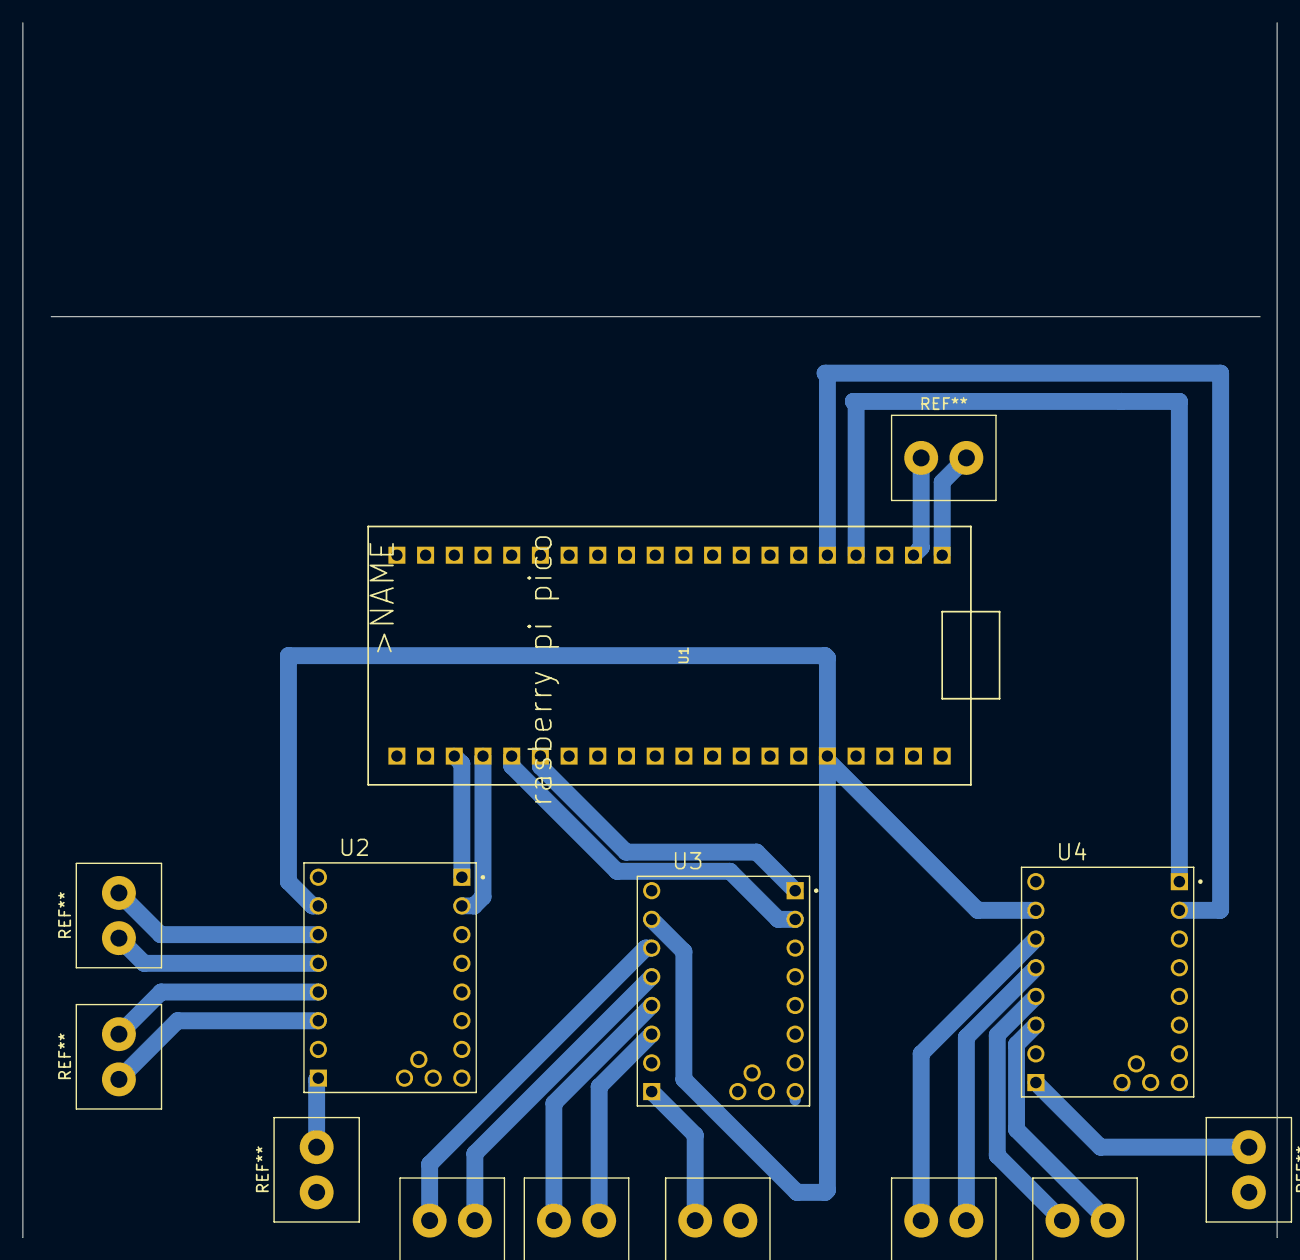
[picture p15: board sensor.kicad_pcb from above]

Board: 2 copper layers, 111.0 x 107.5 mm, 4 parts (0 on the bottom side), 8 nets.

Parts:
U1: RASPBERRY_PI_PICO
U2, U3, U4: TMC2208_SILENTSTEPSTICK; MODULE_TMC2208_SILENTSTEPSTICK

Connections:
DIR: U1.GND3, U2.JP1_1 (DIR)
DIR2: U1.GP19, U3.JP1_2 (STEP)
DIR3: U1.GP2, U1.GP21, U4.JP1_1 (DIR)
GND: U1.GND, U2.JP1_8 (EN), U2.JP2_2 (GND), U2.JP2_8 (GND), U3.JP1_8 (EN), U3.JP2_2 (GND), U3.JP2_8 (GND), U4.JP1_8 (EN), U4.JP2_2 (GND), U4.JP2_8 (GND)
STEP1: U1.GP18, U2.JP1_2 (STEP)
STEP2: U1.GP20, U3.JP1_1 (DIR)
STEP3: U1.GP3, U1.GP22, U4.JP1_2 (STEP)
VIO: U1.3V3, U2.JP2_7 (VIO), U3.JP2_7 (VIO), U4.JP2_7 (VIO)

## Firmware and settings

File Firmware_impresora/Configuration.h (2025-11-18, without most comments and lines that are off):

#pragma once
#define CONFIG_EXAMPLES_DIR "Custom/MakerPi_P3_PRO_SKR14"
#pragma once
#define CONFIGURATION_H_VERSION 02000905
#define STRING_CONFIG_H_AUTHOR "(Lionel, MakerPi P3 PRO - SKR v1.4)" // Who made the changes.
#define SHOW_BOOTSCREEN
  #define MOTHERBOARD BOARD_BTT_SKR_V1_4
#define SERIAL_PORT -1
#define BAUDRATE 115200
#define CUSTOM_MACHINE_NAME "MakerPi P3 PRO"
#define X_DRIVER_TYPE  DRV8825
#define Y_DRIVER_TYPE  TMC2208_STANDALONE
#define Z_DRIVER_TYPE  DRV8825
#define E0_DRIVER_TYPE DRV8825
#define EXTRUDERS 1
#define DEFAULT_NOMINAL_FILAMENT_DIA 1.75
#define TEMP_SENSOR_0 1
#define TEMP_SENSOR_1 0
#define TEMP_SENSOR_2 0
#define TEMP_SENSOR_3 0
#define TEMP_SENSOR_4 0
#define TEMP_SENSOR_5 0
#define TEMP_SENSOR_6 0
#define TEMP_SENSOR_7 0
#define TEMP_SENSOR_BED 1
#define TEMP_SENSOR_PROBE 0
#define TEMP_SENSOR_CHAMBER 0
#define TEMP_SENSOR_COOLER 0
#define TEMP_SENSOR_BOARD 0
#define TEMP_SENSOR_REDUNDANT 0
#define DUMMY_THERMISTOR_998_VALUE  25
#define DUMMY_THERMISTOR_999_VALUE 100
#define TEMP_RESIDENCY_TIME         10  // (seconds) Time to wait for hotend to "settle" in M109
#define TEMP_WINDOW                  1  // (°C) Temperature proximity for the "temperature reached" timer
#define TEMP_HYSTERESIS              3  // (°C) Temperature proximity considered "close enough" to the target
#define TEMP_BED_RESIDENCY_TIME     10  // (seconds) Time to wait for bed to "settle" in M190
#define TEMP_BED_WINDOW              1  // (°C) Temperature proximity for the "temperature reached" timer
#define TEMP_BED_HYSTERESIS          3  // (°C) Temperature proximity considered "close enough" to the target
#define TEMP_CHAMBER_RESIDENCY_TIME 10  // (seconds) Time to wait for chamber to "settle" in M191
#define TEMP_CHAMBER_WINDOW          1  // (°C) Temperature proximity for the "temperature reached" timer
#define TEMP_CHAMBER_HYSTERESIS      3  // (°C) Temperature proximity considered "close enough" to the target
#if TEMP_SENSOR_REDUNDANT
  #define TEMP_SENSOR_REDUNDANT_SOURCE    E1  // The sensor that will provide the redundant reading.
  #define TEMP_SENSOR_REDUNDANT_TARGET    E0  // The sensor that we are providing a redundant reading for.
  #define TEMP_SENSOR_REDUNDANT_MAX_DIFF  10  // (°C) Temperature difference that will trigger a print abort.
#endif
#define HEATER_0_MINTEMP   5
#define HEATER_1_MINTEMP   5
#define HEATER_2_MINTEMP   5
#define HEATER_3_MINTEMP   5
#define HEATER_4_MINTEMP   5
#define HEATER_5_MINTEMP   5
#define HEATER_6_MINTEMP   5
#define HEATER_7_MINTEMP   5
#define BED_MINTEMP        5
#define CHAMBER_MINTEMP    5
#define HEATER_0_MAXTEMP 275
#define HEATER_1_MAXTEMP 275
#define HEATER_2_MAXTEMP 275
#define HEATER_3_MAXTEMP 275
#define HEATER_4_MAXTEMP 275
#define HEATER_5_MAXTEMP 275
#define HEATER_6_MAXTEMP 275
#define HEATER_7_MAXTEMP 275
#define BED_MAXTEMP      120
#define CHAMBER_MAXTEMP  60
#define HOTEND_OVERSHOOT 15   // (°C) Forbid temperatures over MAXTEMP - OVERSHOOT
#define BED_OVERSHOOT    10   // (°C) Forbid temperatures over MAXTEMP - OVERSHOOT
#define COOLER_OVERSHOOT  2   // (°C) Forbid temperatures closer than OVERSHOOT
#define PIDTEMP          // See the PID Tuning Guide at https://reprap.org/wiki/PID_Tuning
#define BANG_MAX 255     // Limits current to nozzle while in bang-bang mode; 255=full current
#define PID_MAX BANG_MAX // Limits current to nozzle while PID is active (see PID_FUNCTIONAL_RANGE below); 255=full current
#define PID_K1 0.95      // Smoothing factor within any PID loop
    #define DEFAULT_Kp  23.34
    #define DEFAULT_Ki   1.85
    #define DEFAULT_Kd  73.55
#define PIDTEMPBED
#define MAX_BED_POWER 255 // limits duty cycle to bed; 255=full current
  #define DEFAULT_bedKp 100.65
  #define DEFAULT_bedKi 14.82
  #define DEFAULT_bedKd 455.69
#define MAX_CHAMBER_POWER 255 // limits duty cycle to chamber heater; 255=full current
  #define PID_FUNCTIONAL_RANGE 10 // If the temperature difference between the target temperature and the actual temperature
  #define PID_EDIT_MENU           // Add PID editing to the "Advanced Settings" menu. (~700 bytes of flash)
  #define PID_AUTOTUNE_MENU       // Add PID auto-tuning to the "Advanced Settings" menu. (~250 bytes of flash)
#define PREVENT_COLD_EXTRUSION
#define EXTRUDE_MINTEMP 170
#define PREVENT_LENGTHY_EXTRUDE
#define EXTRUDE_MAXLENGTH 500
#define THERMAL_PROTECTION_HOTENDS // Enable thermal protection for all extruders
#define THERMAL_PROTECTION_BED     // Enable thermal protection for the heated bed
#define THERMAL_PROTECTION_CHAMBER // Enable thermal protection for the heated chamber
#define THERMAL_PROTECTION_COOLER  // Enable thermal protection for the laser cooling
#define USE_XMIN_PLUG
#define USE_ZMIN_PLUG
#define USE_YMAX_PLUG
#define ENDSTOPPULLUPS
#define X_MIN_ENDSTOP_INVERTING true  // Set to true to invert the logic of the endstop.
#define Y_MIN_ENDSTOP_INVERTING true  // Set to true to invert the logic of the endstop.
#define Z_MIN_ENDSTOP_INVERTING true // Set to true to invert the logic of the endstop.
#define I_MIN_ENDSTOP_INVERTING false // Set to true to invert the logic of the endstop.
#define J_MIN_ENDSTOP_INVERTING false // Set to true to invert the logic of the endstop.
#define K_MIN_ENDSTOP_INVERTING false // Set to true to invert the logic of the endstop.
#define X_MAX_ENDSTOP_INVERTING false // Set to true to invert the logic of the endstop.
#define Y_MAX_ENDSTOP_INVERTING true // Set to true to invert the logic of the endstop.
#define Z_MAX_ENDSTOP_INVERTING false // Set to true to invert the logic of the endstop.
#define I_MAX_ENDSTOP_INVERTING false // Set to true to invert the logic of the endstop.
#define J_MAX_ENDSTOP_INVERTING false // Set to true to invert the logic of the endstop.
#define K_MAX_ENDSTOP_INVERTING false // Set to true to invert the logic of the endstop.
#define ENDSTOP_NOISE_THRESHOLD 4
#define DEFAULT_AXIS_STEPS_PER_UNIT   { 80, 80, 400, 96 }
#define DEFAULT_MAX_FEEDRATE          { 500, 500, 5, 25 }
#define DEFAULT_MAX_ACCELERATION      { 1000, 1000, 100, 5000 }
#define DEFAULT_ACCELERATION           500    // X, Y, Z ... and E acceleration for printing moves
#define DEFAULT_RETRACT_ACCELERATION   500    // E acceleration for retracts
#define DEFAULT_TRAVEL_ACCELERATION    500    // X, Y, Z ... acceleration for travel (non printing) moves
#define DEFAULT_EJERK    5.0  // May be used by Linear Advance
  #define JUNCTION_DEVIATION_MM 0.08 // (mm) Distance from real junction edge
  #define JD_HANDLE_SMALL_SEGMENTS    // Use curvature estimation instead of just the junction angle
#define S_CURVE_ACCELERATION
#define PROBE_MANUALLY
#define NOZZLE_TO_PROBE_OFFSET { 24, -47, -1.5 }
#define PROBING_MARGIN 10
#define XY_PROBE_FEEDRATE (133*60)
#define Z_PROBE_FEEDRATE_FAST (4*60)
#define Z_PROBE_FEEDRATE_SLOW (Z_PROBE_FEEDRATE_FAST / 2)
#define Z_CLEARANCE_DEPLOY_PROBE   10 // Z Clearance for Deploy/Stow
#define Z_CLEARANCE_BETWEEN_PROBES  5 // Z Clearance between probe points
#define Z_CLEARANCE_MULTI_PROBE     5 // Z Clearance between multiple probes
#define Z_PROBE_LOW_POINT          -2 // Farthest distance below the trigger-point to go before stopping
#define Z_PROBE_OFFSET_RANGE_MIN -20
#define Z_PROBE_OFFSET_RANGE_MAX 20
#define X_ENABLE_ON 0
#define Y_ENABLE_ON 0
#define Z_ENABLE_ON 0
#define E_ENABLE_ON 0 // For all extruders
#define DISABLE_X false
#define DISABLE_Y false
#define DISABLE_Z false
#define DISABLE_E false             // Disable the extruder when not stepping
#define DISABLE_INACTIVE_EXTRUDER   // Keep only the active extruder enabled
#define INVERT_X_DIR true
#define INVERT_Y_DIR false
#define INVERT_Z_DIR true
#define INVERT_E0_DIR true
#define INVERT_E1_DIR false
#define INVERT_E2_DIR false
#define INVERT_E3_DIR false
#define INVERT_E4_DIR false
#define INVERT_E5_DIR false
#define INVERT_E6_DIR false
#define INVERT_E7_DIR false
#define X_HOME_DIR -1
#define Y_HOME_DIR 1
#define Z_HOME_DIR -1
#define X_BED_SIZE 300
#define Y_BED_SIZE 300
#define X_MIN_POS 0
#define Y_MIN_POS 0
#define Z_MIN_POS 0
#define X_MAX_POS 300
#define Y_MAX_POS 320
#define Z_MAX_POS 260
#define MIN_SOFTWARE_ENDSTOPS
  #define MIN_SOFTWARE_ENDSTOP_X
  #define MIN_SOFTWARE_ENDSTOP_Y
    #define MIN_SOFTWARE_ENDSTOP_Z
  #define MIN_SOFTWARE_ENDSTOP_I
  #define MIN_SOFTWARE_ENDSTOP_J
  #define MIN_SOFTWARE_ENDSTOP_K
#define MAX_SOFTWARE_ENDSTOPS
  #define MAX_SOFTWARE_ENDSTOP_X
  #define MAX_SOFTWARE_ENDSTOP_Y
  #define MAX_SOFTWARE_ENDSTOP_Z
  #define MAX_SOFTWARE_ENDSTOP_I
  #define MAX_SOFTWARE_ENDSTOP_J
  #define MAX_SOFTWARE_ENDSTOP_K
  #define MESH_BED_LEVELING
#define RESTORE_LEVELING_AFTER_G28
  #define MANUAL_PROBE_START_Z 0.2  // (mm) Comment out to use the last-measured height
  #define ENABLE_LEVELING_FADE_HEIGHT
    #define DEFAULT_LEVELING_FADE_HEIGHT 10.0 // (mm) Default fade height.
  #define SEGMENT_LEVELED_MOVES
  #define LEVELED_SEGMENT_LENGTH 5.0 // (mm) Length of all segments (except the last one)
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

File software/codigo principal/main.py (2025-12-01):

import machine
import time
import json
import uos
from machine import UART, Pin
import sys

PIN_STEP_X = 18
PIN_DIR_X = 17

PINS_STEP_Y = [19, 3]
PINS_DIR_Y = [20, 2]

step_x = machine.Pin(PIN_STEP_X, machine.Pin.OUT)
dir_x = machine.Pin(PIN_DIR_X, machine.Pin.OUT)

steps_y = [machine.Pin(p, machine.Pin.OUT) for p in PINS_STEP_Y]
dirs_y = [machine.Pin(p, machine.Pin.OUT) for p in PINS_DIR_Y]

uart = machine.UART(0, baudrate=115200, rx=machine.Pin(1), tx=machine.Pin(0)) 

DELAY_PULSO_US = 500  
DIR_DERECHA = 1
DIR_IZQUIERDA = 0
DIR_ADELANTE = 1



def set_direccion(pines_dir, direccion):
    """Establece la dirección para uno o varios pines."""
    val = 0 if direccion else 1
    if isinstance(pines_dir, list):
        for pin in pines_dir:
            pin.value(val)
    else:
        pines_dir.value(val)

def toggle_step(pines_step):
    """Genera un flanco de subida y bajada en los pines STEP."""
    # High
    if isinstance(pines_step, list):
        for pin in pines_step: pin.value(1)
    else:
        pines_step.value(1)
    
    time.sleep_us(DELAY_PULSO_US)
    
    # Low
    if isinstance(pines_step, list):
        for pin in pines_step: pin.value(0)
    else:
        pines_step.value(0)
        
    time.sleep_us(DELAY_PULSO_US)

def generar_pulsos(pines_step, pines_dir, direccion, duracion_segundos):
    """
    Abstrae el movimiento generando pulsos durante un tiempo determinado.
    Maneja tanto motores simples (X) como dobles (Y).
    """
    set_direccion(pines_dir, direccion)
    
    start = time.ticks_ms()
    
    while time.ticks_diff(time.ticks_ms(), start) < (duracion_segundos * 1000):
        toggle_step(pines_step)

def obtener_lectura_lidar():
    HEADER_1 = 0x55 
    HEADER_2 = 0xAA
    FOOTER   = 0xFA
    RESPONSE_LEN = 8 
    CMD_MEASURE_DISTANCE = b'\x55\xAA\x81\x00\xFA' 

    LIDAR_STABILIZATION_MS = 200
    RETRY_DELAY_MS = 25
    
    """
    Bucle infinito hasta obtener una lectura válida.
    Basado en la lógica robusta de 'request-response'.
    """
    total_attempts = 0
    sys.stdout.write("   [LIDAR] Buscando dato válido...\n")
    
    
    if uart.any():
        uart.read()

while True: 
        total_attempts += 1
        
       
        uart.write(CMD_MEASURE_DISTANCE)
        
        
        time.sleep_ms(LIDAR_STABILIZATION_MS)
        
        count = uart.any()
        
        
        if count >= RESPONSE_LEN:
            recv = uart.read(RESPONSE_LEN)
            
            
            if (recv and len(recv) == RESPONSE_LEN and 
                recv[0] == HEADER_1 and 
                recv[1] == HEADER_2 and 
                recv[7] == FOOTER): 
                
                
                distance = (recv[4] * 256) + recv[5]
                if distance > 0:
                    sys.stdout.write('   [Dato ÚNICO] -> Distancia: %5d mm. Total intentos: %d\n' % 
                                     (distance, total_attempts))
                    
                    
                    if uart.any(): uart.read()
                    
                    
                    return distance, total_attempts
        
        
        if uart.any():
            uart.read()
            
        
        if total_attempts % 10 == 0:
            sys.stdout.write('   [ATTEMPT %d] -> FALLO. Reintentando...\n' % total_attempts)
            
        time.sleep_ms(RETRY_DELAY_MS)

def guardar_dato(x, y, z):
    """Guarda la tupla en el archivo JSONL (JSON Lines)."""
    linea = json.dumps({"x": x, "y": y, "z": z}) + "\n"
    try:
        
        with open('scan_data.json', 'a') as f:
            f.write(linea)
            f.flush() 
            uos.sync() 
    except OSError as e:
        print(f"Error escribiendo archivo: {e}")

def limpiar_archivo():
    print(f"--- Limpiando archivo ---")
    with open('scan_data.json', 'w') as f:
        pass 
    print("Archivo listo.")

def main():
    limpiar_archivo() 
    print("Iniciando Escáner 3D...")
    
    coord_y = 0
    
    
    while True:
        print(f"--- Iniciando Fila en Y={coord_y} ---")
        
        coord_x = 0
        tiempo_fila_inicio = time.time()
        movimientos_realizados = 0 
        
        
        while (time.time() - tiempo_fila_inicio) < 120:
            
            
            z, intentos = obtener_lectura_lidar()
            
            
            print(f"Guardando: X={coord_x}, Y={coord_y}, Z={z}")
            guardar_dato(coord_x, coord_y, z)
            
            
            generar_pulsos(step_x, dir_x, DIR_DERECHA, duracion_segundos=1.0)
            
           
            coord_x += 5
            movimientos_realizados += 1
            
        
        print("Fin de tiempo de fila. Retornando carro X...") 
        tiempo_retorno = movimientos_realizados * 1.0
        generar_pulsos(step_x, dir_x, DIR_IZQUIERDA, duracion_segundos=tiempo_retorno)
        
        
        coord_x = 0
        
        
        print(f"Avanzando eje Y...")
        
        generar_pulsos(steps_y, dirs_y, DIR_ADELANTE, duracion_segundos=2.0)

        coord_y += 10 

if __name__ == "__main__":
    
    try:
        if 'scan_data.json' not in uos.listdir():
            with open('scan_data.json', 'w') as f:
                pass
    except Exception:
        pass 
            
    try:
        main()
    except KeyboardInterrupt:
        print("Escaneo detenido por el usuario.")

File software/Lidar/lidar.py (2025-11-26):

import serial.tools.list_ports
import time
import numpy as np
import serial
import struct

ports = serial.tools.list_ports.comports()
for p in ports:
    print(p.device)
print(len(ports), 'ports found')

ser = serial.Serial()
ser.port = '/dev/ttyS0'
ser.baudrate = 115200

cmd = bytes.fromhex('55 AA 81 00 FA')

def getLidarData():
    while True:
        ser.write(cmd)
        count = ser.in_waiting

        if count > 7:
            recv = ser.read(8)
            ser.reset_input_buffer()
            if recv[0] == 0x55 and recv[1] == 0xAA and recv[7] == 0xFA:
                
                distance = struct.unpack('>H', recv[4:6])[0] 
                
                print('distance = %5d mm' % (distance))
                ser.reset_input_buffer()
                time.sleep(0.1)
        else:
            time.sleep(0.1)

if __name__ == '__main__':
	try:
		if ser.is_open == False:
			try:
				ser.open()
			except:
				print('Open COM failed!')
		getLidarData()
	except KeyboardInterrupt:
		if ser != None:
			ser.close()

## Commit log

2025-09-17 Create Carpeta de Campo.txt
2025-09-23 Mes de la primavera🌈🌸
2025-10-20 arreglando el pcb
    [sensor.kicad_pcb]
2025-10-21 Subiendo Mes de Abril
2025-10-21 Rename Abril.md to Documentacion/Carpeta de campo/Abril.md
2025-10-21 Subiendo Mes de Agosto
2025-10-21 Subiendo Mes de Mayo
2025-10-21 30 de noviembre
2025-10-21 Create Manual de Usuario
2025-10-21 Rename Manual de Usuario to Manual de Usuario.md
2025-10-21 Subir logo de la matelurgia
2025-10-21 creando el encabezado
2025-10-21 Update Manual de Usuario.md
2025-10-22 Tornillos y destornilladores
    Se magrego la seccion tornillos y dstornilladores
2025-10-31 Correjir PPCB
    [sensor.kicad_pcb]
2025-10-31 Cambio de pi 4 a pi pico
    [sensor.kicad_pcb]
2025-10-31 Subir Manual de usuario y carpoeta tecnica
2025-11-12 Subir soportes 3D
    [Dibujo1.stl, Soporte_del_otro_eje.stl, soporte_varilla_eje_x_1.stl]
2025-11-18 Subir factura de la placa de cobre
2025-11-18 Rename dba2b513-6633-446f-9577-a1ffcd4fef4a.jpg to 17 de junio.jpg
2025-11-18 Factura de las varillas
2025-11-18 Factura de cables
2025-11-18 Factura corte de varillas
2025-11-18 Factura placa de cobre y cables
2025-11-18 Factura de SD
2025-11-18 Add Configuration.h for printer firmware settings
    [Configuration.h]
2025-11-18 Rename 16 de septiembre.jpg to 16-09.jpg
2025-11-18 Rename 27 de septiembre.jpg to 27-09.jpg
2025-11-18 Rename 4 de septiembre.jpg to 4-09.jpg
2025-11-18 Rename 5 de septiembre.jpg to 5-09.jpg
2025-11-18 Rename 9 de julio.jpg to 9-07.jpg
2025-11-18 Rename 21 de julio.jpg to 21-07.jpg
2025-11-18 Rename 17 de junio.jpg to 17-06.jpg
2025-11-18 Rename 18 de agosto.jpg to 18-08.jpg
2025-11-18 Factura drivers
2025-11-18 Factura placa de cobre
2025-11-18 Rename 21 de octubre.jpg to 21-10.jpg
2025-11-18 Rename 4 de noviembre.jpg to 4-11.jpg
2025-11-18 Rename 11 de septiembre.jpg to 11-09.jpg
2025-11-18 Create elemenos de alcance inconclusos
2025-11-18 Diapositiva de presentación
2025-11-22 Rename Dibujo1.dwg to chasis escaner.dwg
    [chasis escaner.dwg]
2025-11-22 Rename Video de WhatsApp 2025-11-22 a las 15.33.45_e74085b7.mp4 to probando motores
2025-11-22 Rename Imagen de WhatsApp 2025-11-22 a las 15.33.41_6b8152f8.jpg to paralelo de sensores
2025-11-22 Rename Imagen de WhatsApp 2025-11-22 a las 15.33.40_7c466ca6.jpg to probando motores con la placa skr1.4
2025-11-22 Rename Imagen de WhatsApp 2025-11-22 a las 15.33.40_4c03e847.jpg to probando ventiladores
2025-11-22 Rename Video de WhatsApp 2025-11-22 a las 15.33.45_e74085b7 (1).mp4 to primera impresion
2025-11-22 Rename fotos_impresora/paralelo de sensores to Documentacion/Imagenes/Impresora/paralelo de sensores
2025-11-22 Rename fotos_impresora/probando motores to Documentacion/Imagenes/Impresora/probando motores
2025-11-22 Rename fotos_impresora/probando motores con la placa skr1.4 to Documentacion/Imagenes/Impresoraprobando motores con la placa skr1.4
2025-11-22 Rename Documentacion/Imagenes/Impresoraprobando motores con la placa skr1.4 to Documentacion/Imagenes/Impresora/probando motores con la placa skr1.4
2025-11-25 Rename Manual de usuario (2).pdf to Manual de usuario.pdf
